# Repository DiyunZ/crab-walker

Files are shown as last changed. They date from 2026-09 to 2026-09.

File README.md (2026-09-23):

# Crab Walker

A single-motor walking robot that picks up a payload, crosses grass, pebbles and hills, and drops it at the target. Built for ME 370 Mechanical Design I at the University of Illinois (Project Dawnstar II), spring 2026, by Team 12: Daniel Cai, Zac Vazquez, Shenbo Xue and Diyun Zheng.

<p>
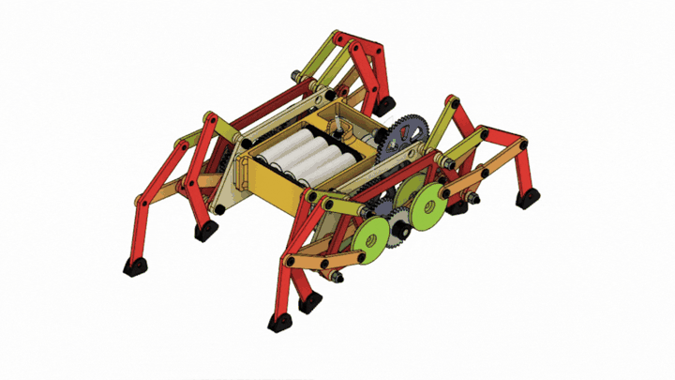
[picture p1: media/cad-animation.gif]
CAD animation of the Crab Walker walking

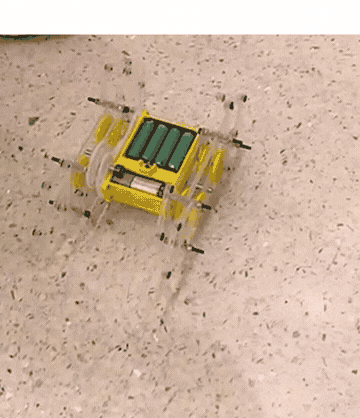
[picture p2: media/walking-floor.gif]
The built walker walking on the floor

</p>

## The brief

- One motor and one degree of freedom for everything: walking, grabbing and releasing.
- Fit inside 18 x 18 x 30 cm in one configuration.
- Pick up a payload in the loading zone, carry it about 110 cm across the terrain of our choice, and drop it in the unloading zone, all within 15 minutes.
- $60 budget. We spent $56.30.

We chose the grass, pebbles and hills route. In the final evaluation the walker completed the mission and also cleared the steeper hill and rocky routes.

<p>
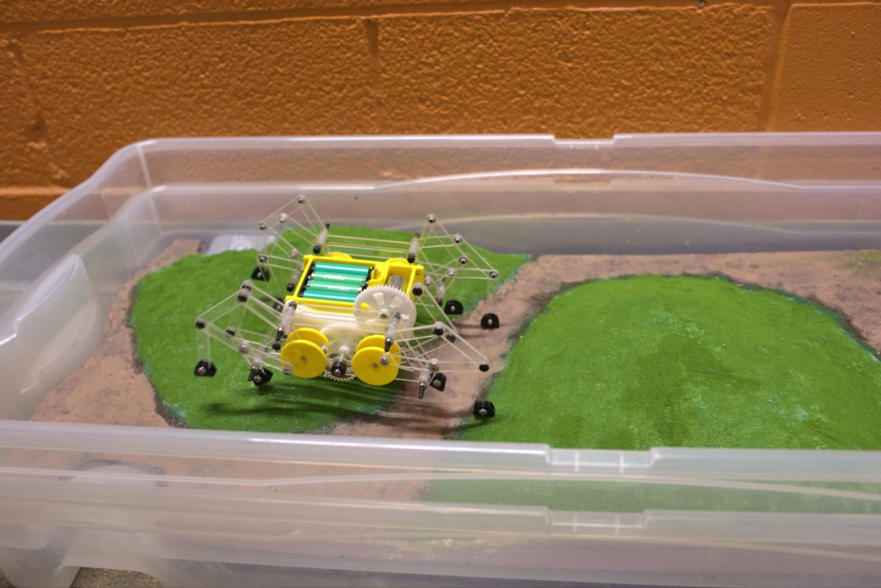
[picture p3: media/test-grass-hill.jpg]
Walker on the grass and hill section

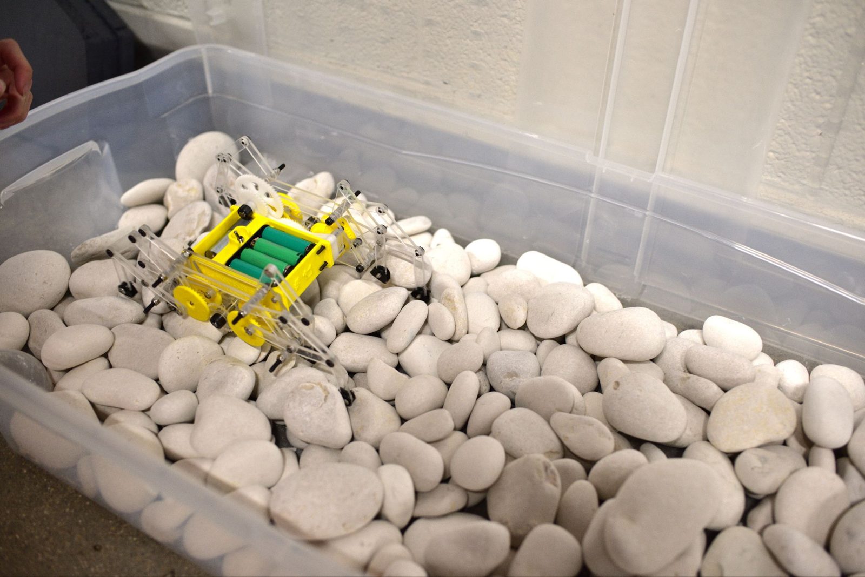
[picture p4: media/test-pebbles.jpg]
Walker on pebbles

</p>
<p>
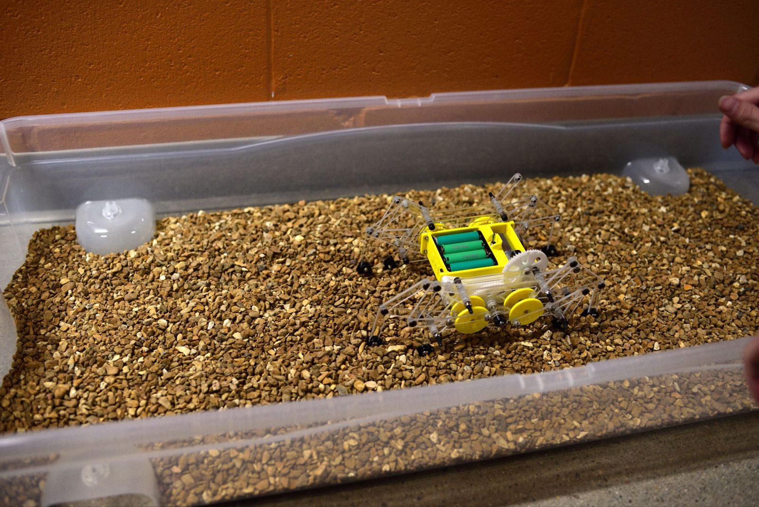
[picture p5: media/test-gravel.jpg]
Walker on gravel

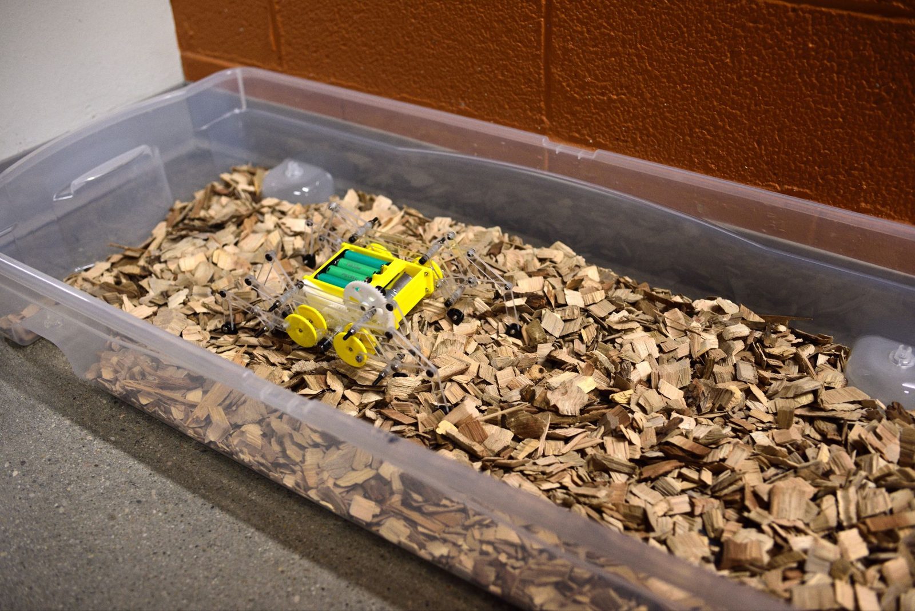
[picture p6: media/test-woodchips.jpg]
Walker on wood chips

</p>

## Design

### Legs: eight Klann linkages, four sets per side

The Klann linkage turns the motor's rotation into a walking step with no control electronics. Compared with the alternatives we looked at, it lifts the foot higher for obstacles, keeps the foot on the ground longer for traction, and does not lift the whole body every step, which keeps motor torque low.

<p>
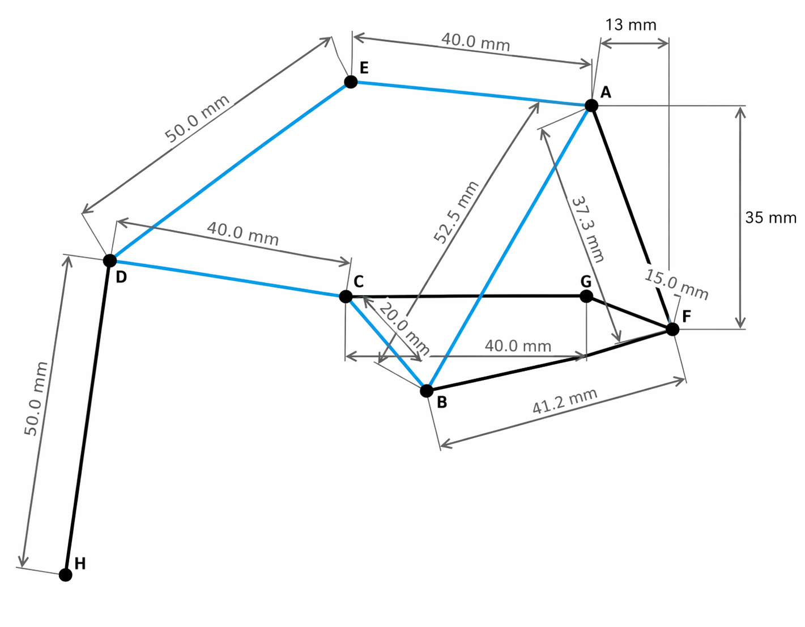
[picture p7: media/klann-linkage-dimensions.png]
Klann linkage link dimensions in millimetres

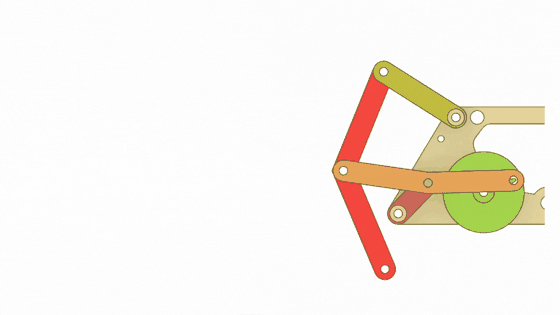
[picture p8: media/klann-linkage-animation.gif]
Animation of one Klann linkage cycle

</p>

Each side carries four leg sets arranged with a 180 degree phase offset, so at least four feet touch the ground at all times. That is what keeps the payload level on loose or uneven terrain.

<p>
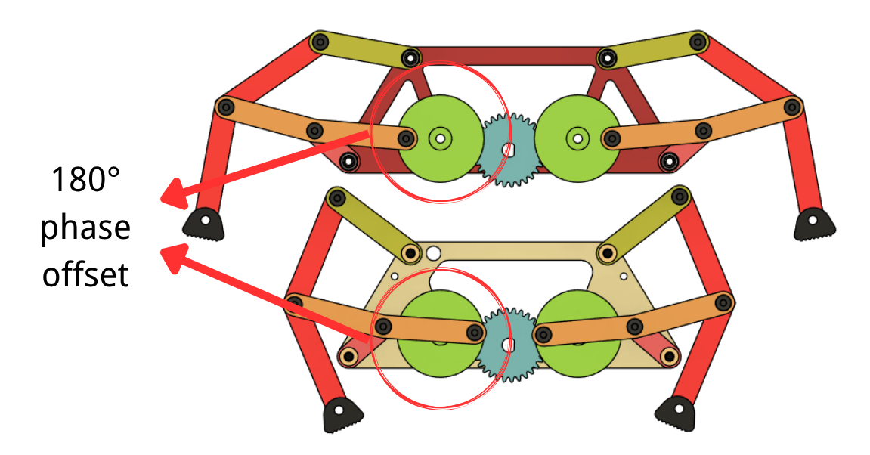
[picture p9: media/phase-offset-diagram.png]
Two leg layers with a 180 degree phase offset

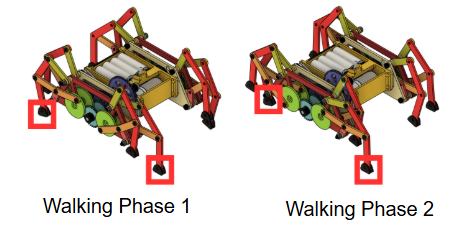
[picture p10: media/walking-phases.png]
Feet in contact during the two walking phases

</p>

### Drive train

A single input gear drives every leg crank through D-shafts, with a 2:1 reduction for the legs. A dynamic force analysis of the linkage located the peak-torque crank angles and toggle positions, which set the gear ratio and confirmed the motor's power margin.

<p>
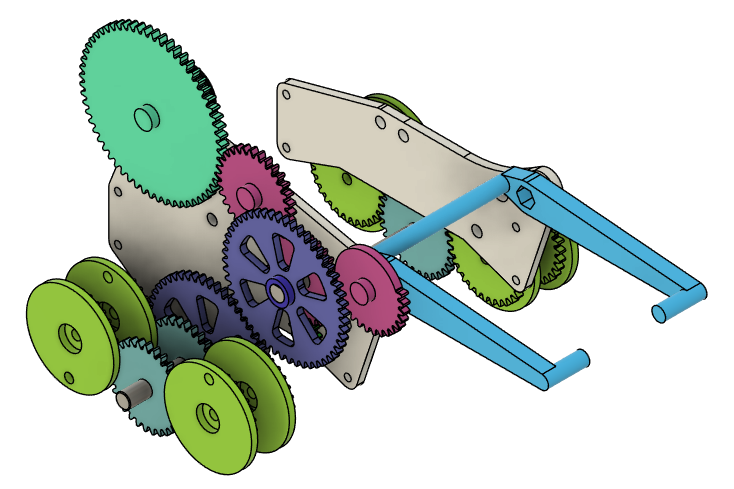
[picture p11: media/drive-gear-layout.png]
Drive gear layout

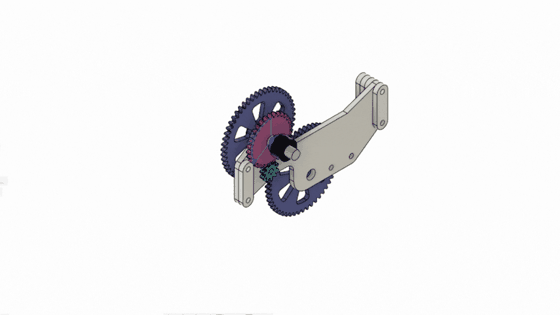
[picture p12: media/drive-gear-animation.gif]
Animation of the gear train

</p>
<p>
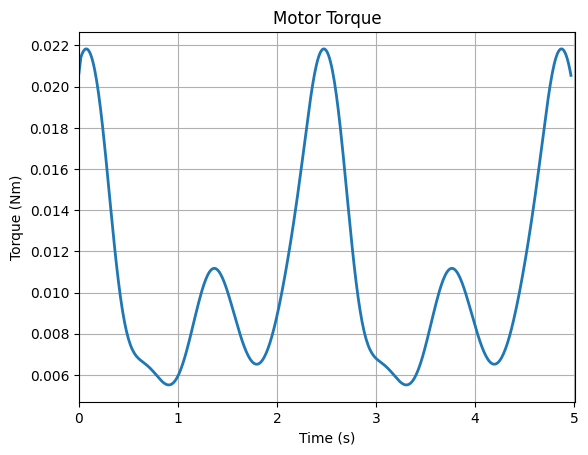
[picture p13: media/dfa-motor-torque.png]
Motor torque over one cycle from the dynamic force analysis

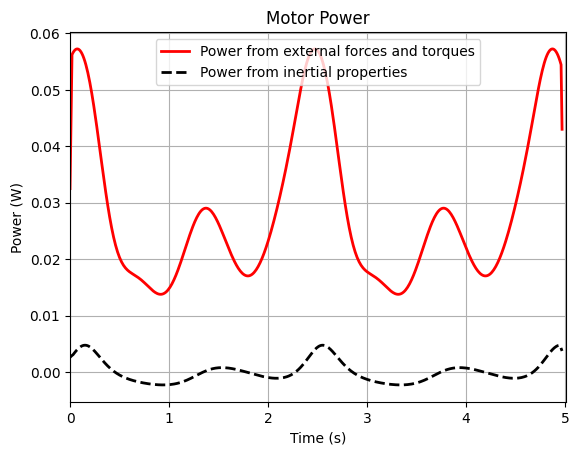
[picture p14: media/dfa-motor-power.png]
Motor power split between external loads and link inertia

</p>

### Payload scoop and drop-off gate, on the same shaft

A U-shaped scoop arm lifts the payload by its side fins. Its driving gear has teeth on only part of its circumference, so once the arm has thrown the payload onto the slope it disengages and cannot stall the train. The payload slides down to a gate held by rubber bands on a reel; a 1:5 reel drive winds the bands in as the walker advances and opens the gate at the unloading zone.

<p>
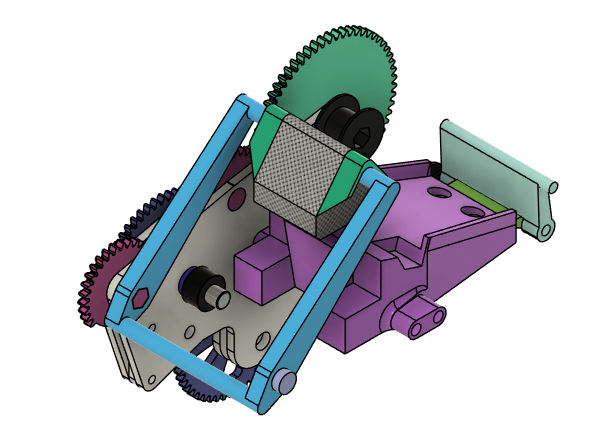
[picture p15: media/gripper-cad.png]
Scoop arm CAD

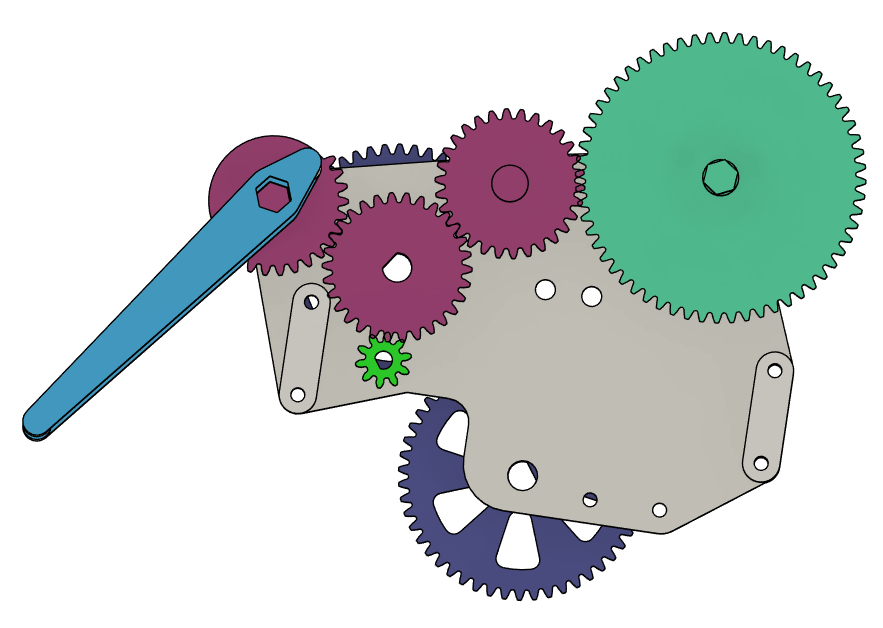
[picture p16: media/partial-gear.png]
Partial gear that disengages after drop-off

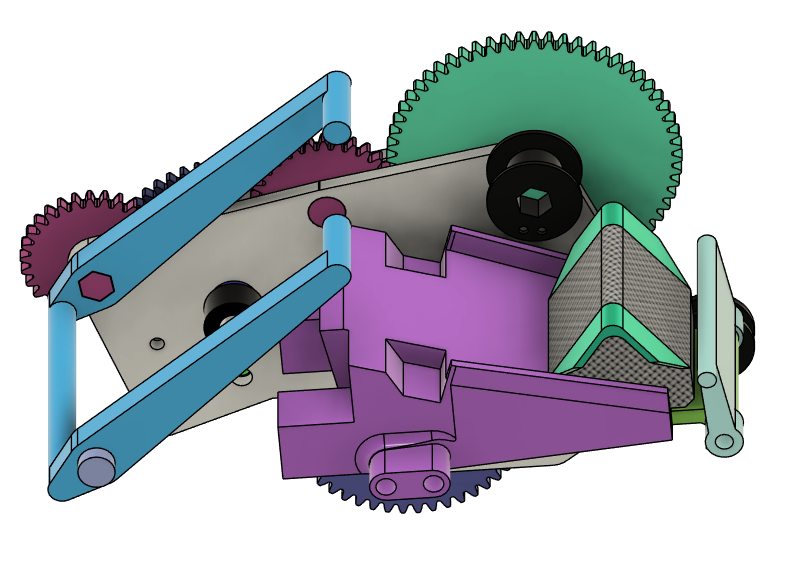
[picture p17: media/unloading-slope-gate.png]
Slope and gate for unloading

</p>

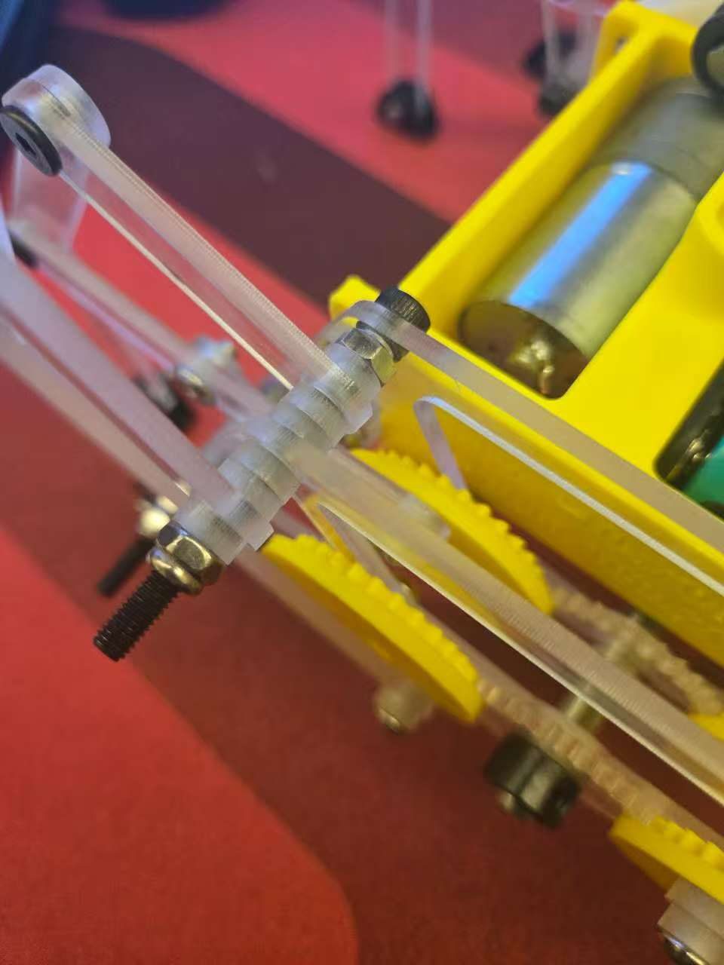
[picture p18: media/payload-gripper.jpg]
Payload held by the scoop arm on the built walker


## Fabrication

The frame, linkage layers and gears are laser-cut 1/8 inch acrylic; the feet, the payload parts and the scoop are 3D-printed PLA. Layers are stacked on M4 screws and spacers, gears are cut to the D-shaft profile, and joints use low-profile screws tapped into the acrylic.

<p>
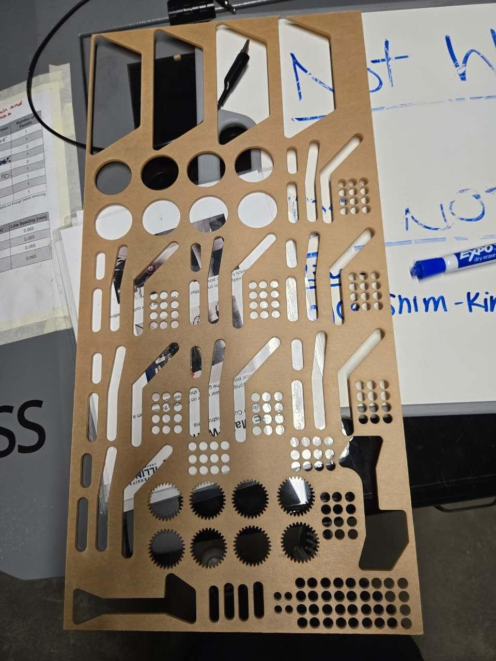
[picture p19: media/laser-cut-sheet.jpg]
Laser-cut acrylic sheet

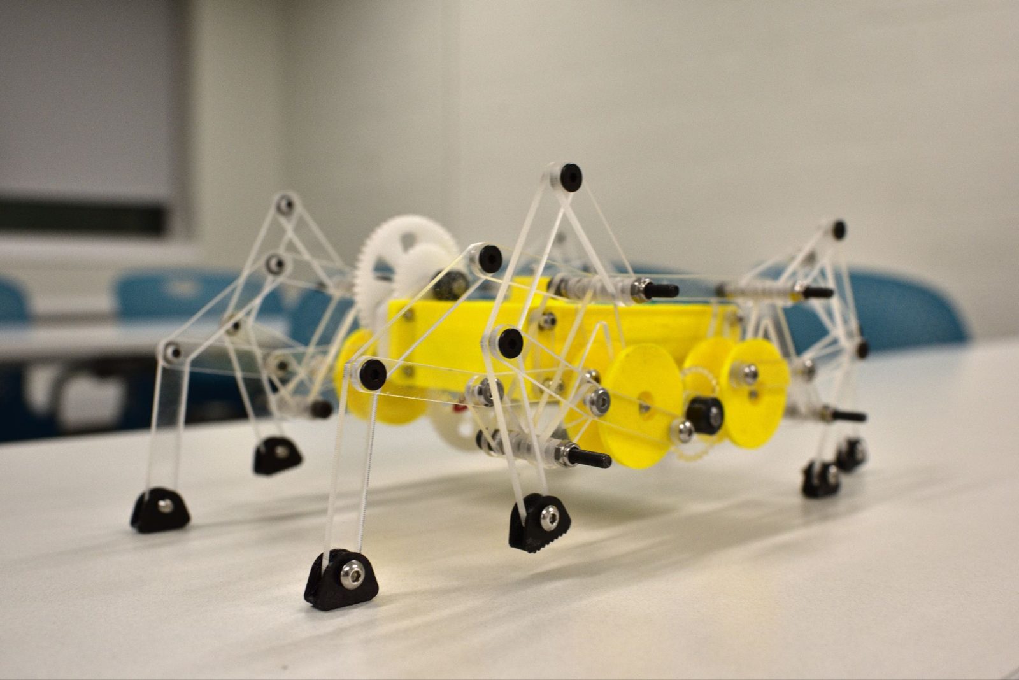
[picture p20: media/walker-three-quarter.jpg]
Finished walker, three-quarter view

</p>
<p>
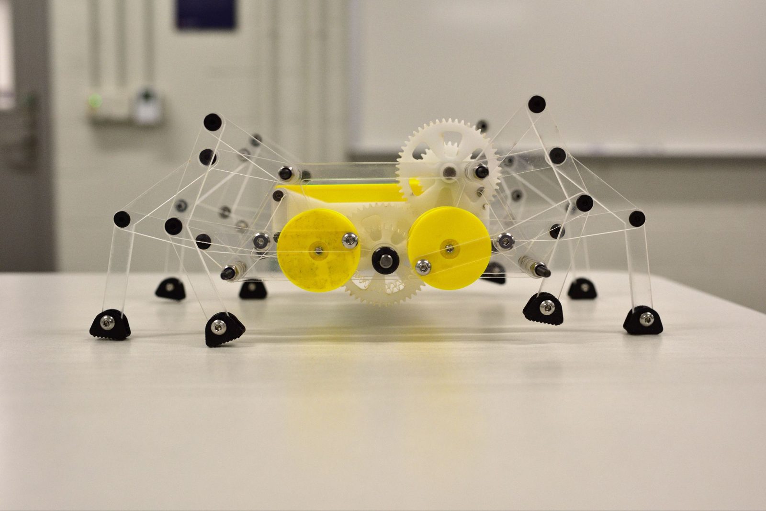
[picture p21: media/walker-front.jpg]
Finished walker, front view

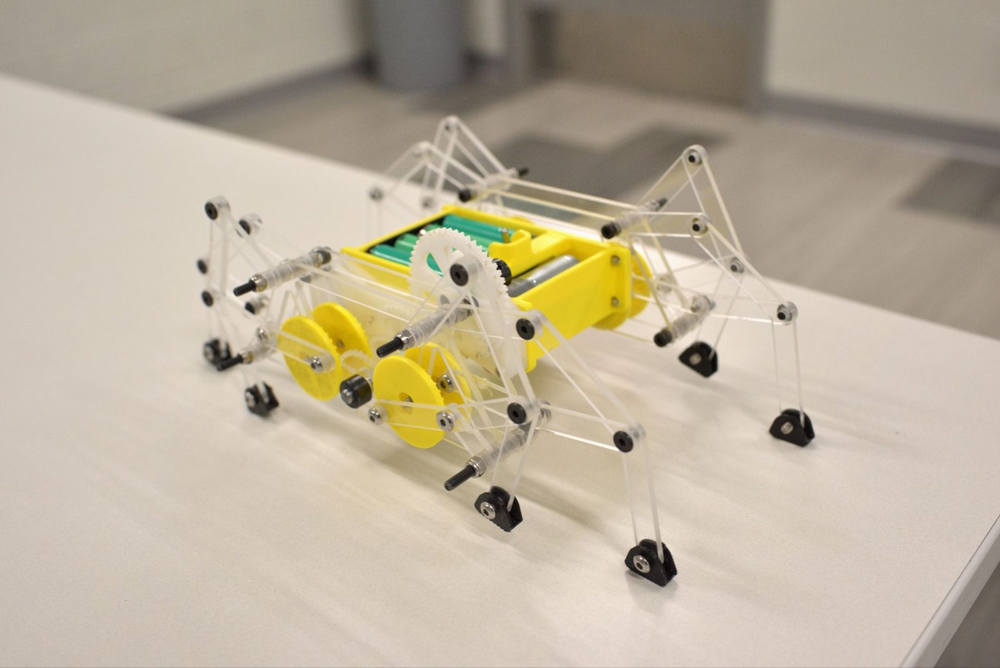
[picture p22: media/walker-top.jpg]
Finished walker, top view

</p>

## Drawings

<p>
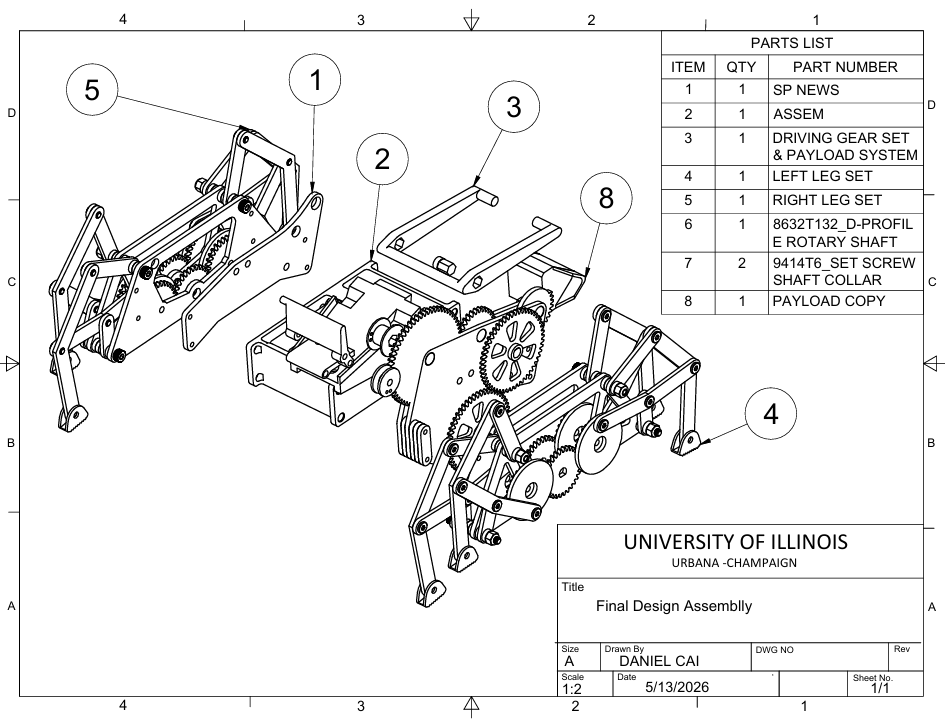
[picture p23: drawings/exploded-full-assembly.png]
Exploded view of the full assembly

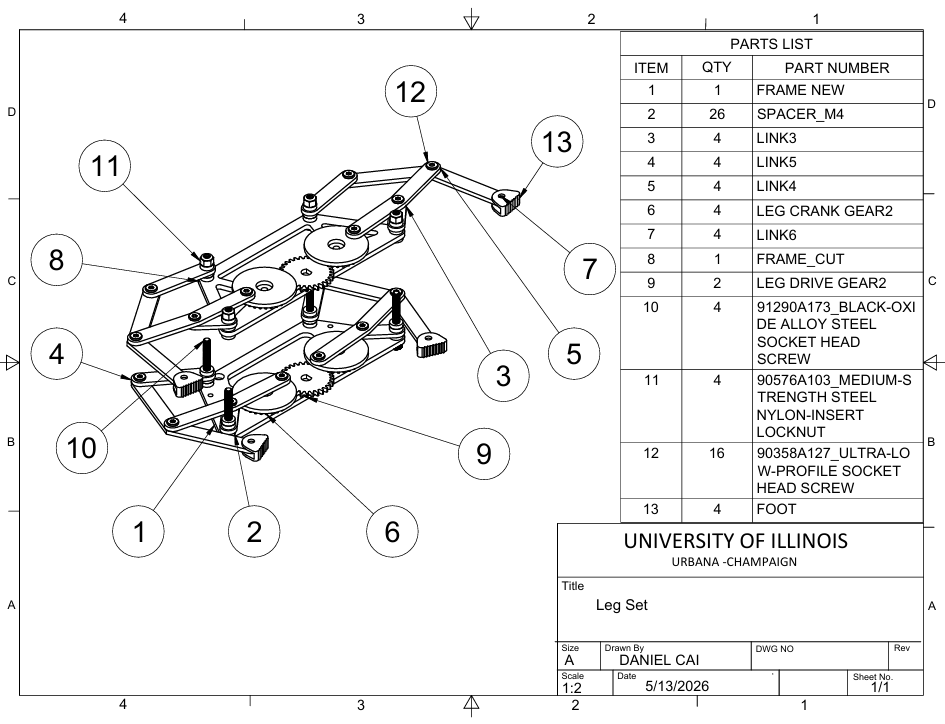
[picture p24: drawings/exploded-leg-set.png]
Exploded view of one leg set

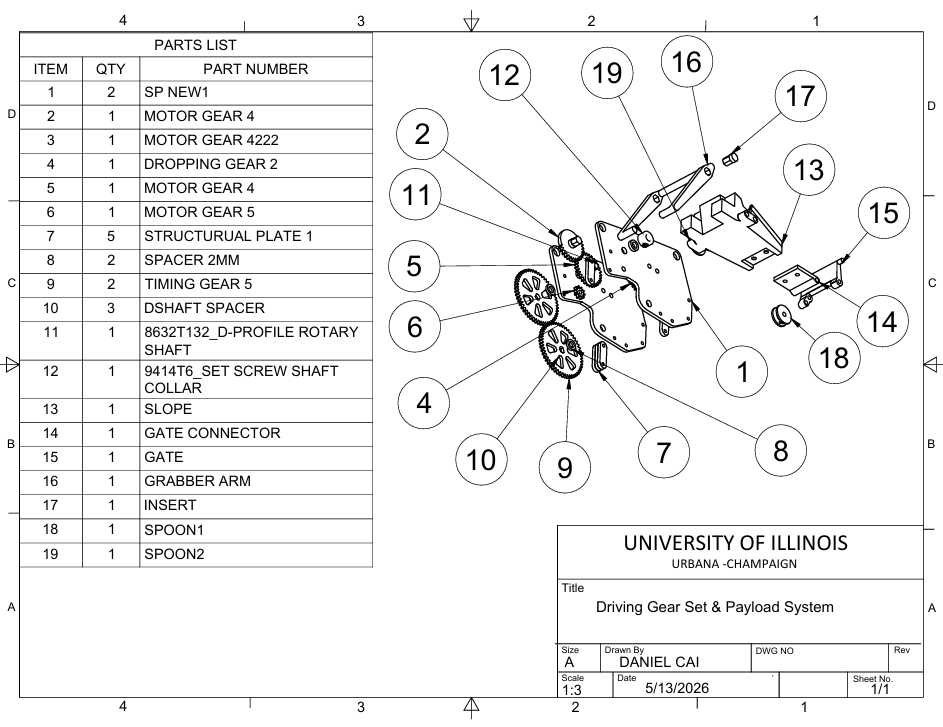
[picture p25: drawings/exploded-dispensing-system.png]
Exploded view of the dispensing system

</p>

## Files

| Folder | Contents |
|---|---|
| `drawings/` | Exploded assembly drawings |
| `media/` | Photos, CAD renders and animations used above |

## Credits

Team 12, ME 370 spring 2026: Daniel Cai, Zac Vazquez, Shenbo Xue, Diyun Zheng. Course staff provided the modular power unit; everything else was designed and built by the team. Parts and manufacturing through the Jackson Innovation Studio at UIUC.

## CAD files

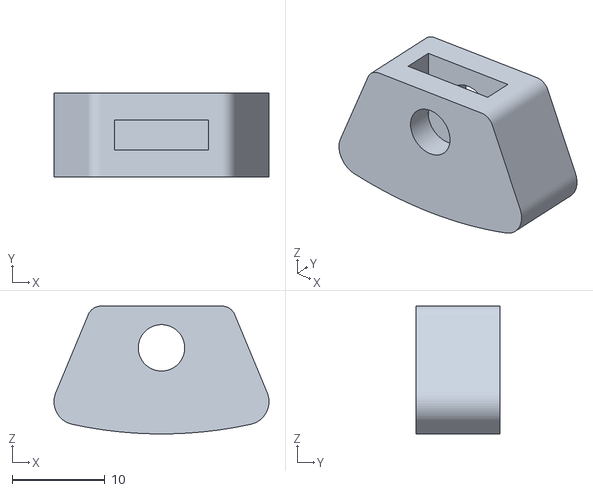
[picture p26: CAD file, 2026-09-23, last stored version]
fabrication/3d-print/foot3.stl
23.2 x 9.00 x 13.8

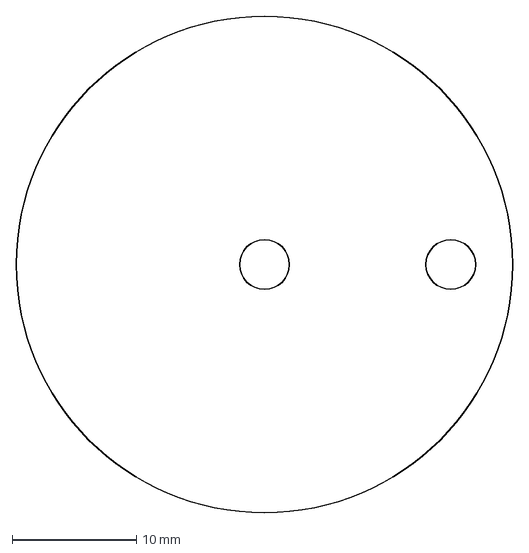
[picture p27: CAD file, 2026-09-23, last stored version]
fabrication/laser-cut/Leg Crank.dxf
40.0 x 40.0 mm

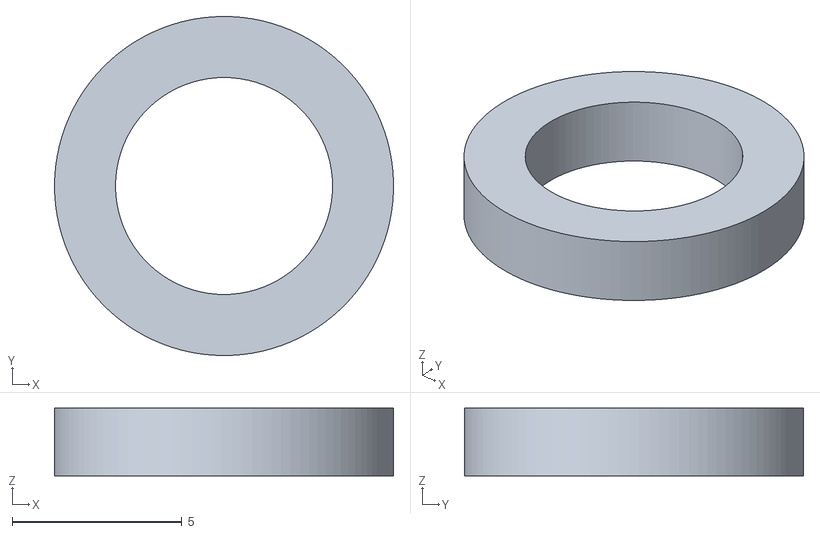
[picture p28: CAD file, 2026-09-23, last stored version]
fabrication/3d-print/Spacer 2mm.stl
10.00 x 10.00 x 2.00

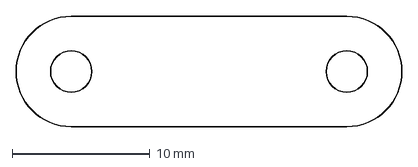
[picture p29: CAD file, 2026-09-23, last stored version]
fabrication/laser-cut/Structural Plate1.dxf
28.0 x 8.00 mm

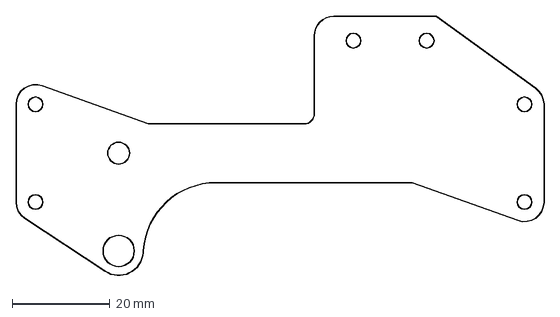
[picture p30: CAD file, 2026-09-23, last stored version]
fabrication/laser-cut/Structual Plate4.dxf
108.0 x 53.3 mm

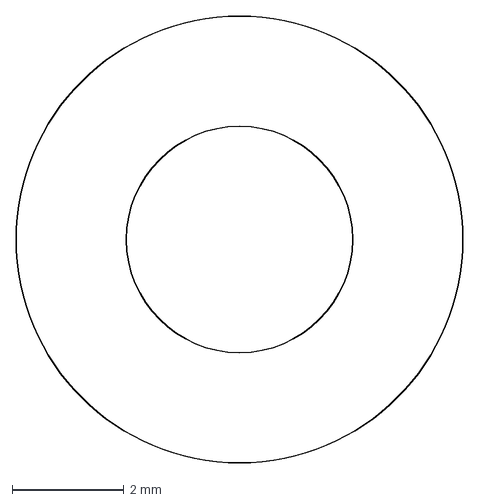
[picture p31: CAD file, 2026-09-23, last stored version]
fabrication/laser-cut/SpacerM4.dxf
8.00 x 8.00 mm

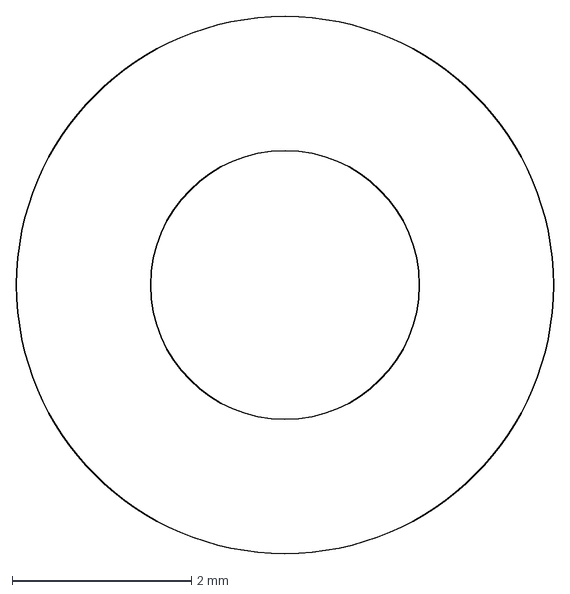
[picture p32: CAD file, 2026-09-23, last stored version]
fabrication/laser-cut/M3 Spacer.dxf
6.00 x 6.00 mm

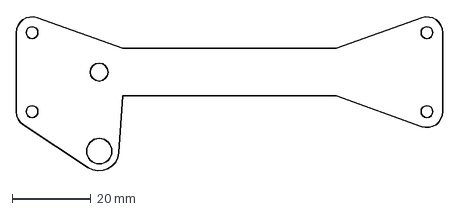
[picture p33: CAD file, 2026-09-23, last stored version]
fabrication/laser-cut/Structual Plate 3.dxf
108.0 x 39.5 mm

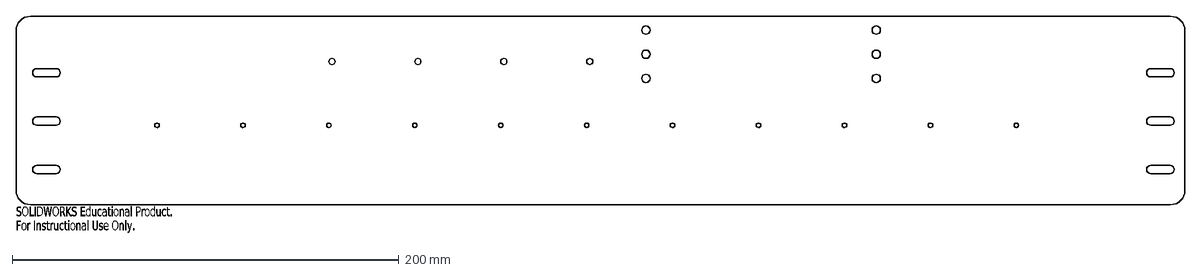
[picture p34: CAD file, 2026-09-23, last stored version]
fabrication/laser-cut/Mounting Plate.DXF
SOLIDWORKS Educational Product.
For Instructional Use Only.

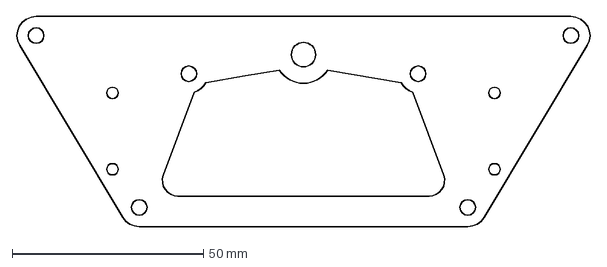
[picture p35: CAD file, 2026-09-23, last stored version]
fabrication/laser-cut/Frame3.dxf
150.5 x 55.0 mm

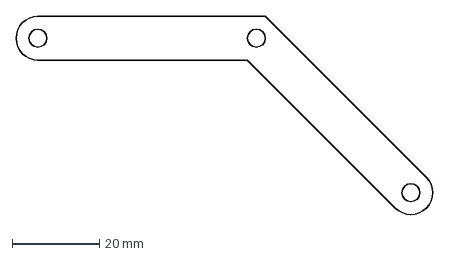
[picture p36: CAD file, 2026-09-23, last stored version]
fabrication/laser-cut/Link 6.dxf
95.8 x 45.8 mm

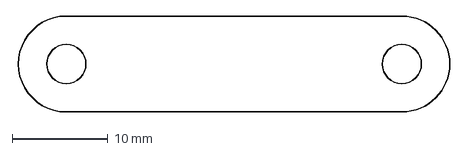
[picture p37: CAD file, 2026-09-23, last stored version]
fabrication/laser-cut/Link 5.dxf
45.2 x 10.0 mm

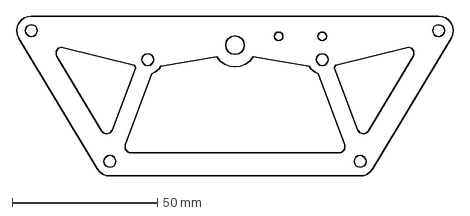
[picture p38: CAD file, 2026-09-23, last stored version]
fabrication/laser-cut/Frame.dxf
150.5 x 55.0 mm

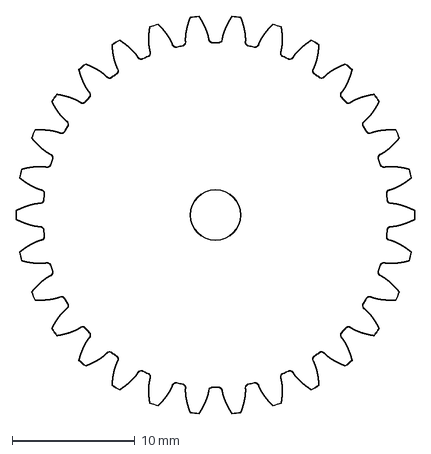
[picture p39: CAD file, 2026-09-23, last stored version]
fabrication/laser-cut/Leg Crank Gear.dxf
32.4 x 32.3 mm

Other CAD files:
fabrication/3d-print/foot2.stl
fabrication/laser-cut/Link 4.dxf
fabrication/laser-cut/Panel.DXF
fabrication/laser-cut/Link 3.dxf

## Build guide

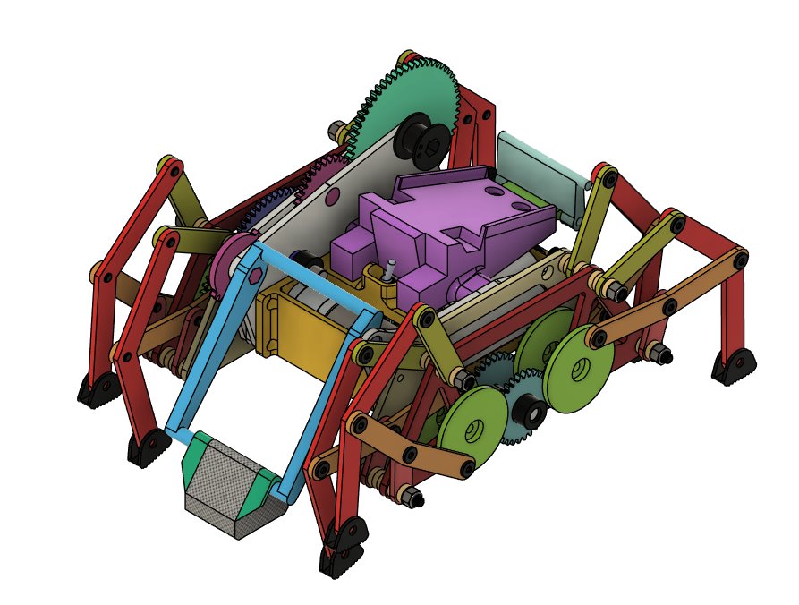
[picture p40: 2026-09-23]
media/cad-full-assembly.png

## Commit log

2026-09-23 Initial release
    [Frame.dxf, Frame3.dxf, Leg Crank Gear.dxf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]
2026-09-23 Remove Dawnstar I section and fabrication files
    [Frame.dxf, Frame3.dxf, Leg Crank Gear.dxf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]
